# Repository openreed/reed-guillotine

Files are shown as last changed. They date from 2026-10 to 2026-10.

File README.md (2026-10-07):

# Reed Guillotine

[Read in English](README.md) | [[以中文阅读](README_CN.md)]

> OpenSCAD parametric model source for the OpenReed reed guillotine.
> For product info, visit the [project page](https://openreed.github.io/oboe/reed-guillotine/).

---

## Table of Contents

- [Reed Guillotine](#reed-guillotine)
  - [Table of Contents](#table-of-contents)
  - [Generating 3D Model Files](#generating-3d-model-files)
    - [Prerequisites](#prerequisites)
    - [Using the Render Script](#using-the-render-script)
    - [Pre-generated Files](#pre-generated-files)
  - [Parameter Reference](#parameter-reference)
  - [3D Printing Tips](#3d-printing-tips)
  - [Project Structure](#project-structure)
  - [License](#license)

---

## Generating 3D Model Files

### Prerequisites

- [OpenSCAD](https://openscad.org/) (recommended: `brew install openscad` on macOS)
- Python 3
- [BOSL2](https://github.com/revarbat/BOSL2) library — install via OpenSCAD's Library Manager

### Using the Render Script

The project provides `render.py` to render all parts to STL in one command:

```bash
# Render all parts of the oboe/English horn version
python render.py obeh

# Render only specific parts (comma-separated)
python render.py obeh --parts body,lid,handle

# Render assembly only
python render.py obeh --assembly-only

# Custom output directory
python render.py obeh --output ./my_stls

# List available model versions
python render.py --list-versions
```

STL files are saved to `3D_files/obeh/` by default.

### Pre-generated Files

Pre-generated `.3mf` files are also available for direct download from MakerWorld.

---

## Parameter Reference

All parameters are defined in `libs/obeh/params.scad`. See the [Chinese README](README_CN.md#参数说明) for the complete parameter table with descriptions.

The assembly uses one fixed lower blade and a solid upper cutting block. The block uses `cutting_block_wedge_height=3` mm and `cutting_block_tip_radius=1.2` mm. Open `assembly.scad` or run `python3 render.py obeh --assembly-only` to render the assembly. `blade_holder.scad` renders only the lower blade clamp.

The cutting block forms its rounded wedge with `hull()` between the block shoulder and a cylinder. The radius may exceed half the wedge height: the cylinder can overlap the solid main block. Radius changes preserve the finished block height (`blade_width`) and contact ridge position. Positive `blade_engagement_tolerance` leaves clearance at the lowest position, while negative values allow engagement. This is the signed height difference between the block's lowest point and the lower blade at the geometric spring-seat stop. Actual travel also depends on the installed spring and handle.

`cutting_block_front_back_fit_tolerance` shifts the block's contact edge along x relative to the lower blade. The body, slider positions in the assembly, and lower blade clamp stay fixed. The independent lower clamp thickness, `blade_clamp_height`, defaults to 1.885 mm to preserve the existing body dimensions. Block slider and slot parameters use the `cutting_block_` prefix.

The parameters are organized into the following groups:

| Group | Description |
|---|---|
| Tolerances | Fine-tune part fit and assembly clearance |
| Base Parameters | Main body dimensions and fillets |
| Slot Parameters | Reed holder slot geometry |
| Scale Parameters | Cutting scale markings |
| Blade Parameters | Standard utility blade (009 RD) dimensions |
| Blade Holder Parameters | Blade clamp geometry |
| Cutting Block Parameters | Block sliders, wedge height, and contact edge radius |
| Spring Parameters | Spring seat dimensions |
| Wall Parameters | Side walls and screw holes |
| Handle Parameters | Handle and axle geometry |
| Lid Parameters | Top lid dimensions |
| Reed Holder Parameters | Reed holder, staple slot, and mandrel dimensions |

---

## 3D Printing Tips

- Use ≤ 0.12 mm layer height for the lower blade clamp, cutting block, and reed holder
- Print the cutting block with its flat back on the bed and the rounded wedge facing up
- Enable supports for the reed holder
- Multi-color printing makes scale markings more readable
- **PETG** is recommended for better durability

---

## Project Structure

```
├── README.md              # This file
├── render.py              # STL rendering script
├── draft.scad / draft2.scad  # Scratch files
├── libs/
│   ├── obeh/              # Oboe / English Horn version
│   │   ├── params.scad    # All parameter definitions
│   │   ├── assembly.scad  # Assembly model
│   │   └── modules/       # Individual part modules
│   │       ├── body.scad
│   │       ├── blade.scad
│   │       ├── blade_holder.scad
│   │       ├── cutting_block.scad
│   │       ├── handle.scad
│   │       ├── lid.scad
│   │       └── reed_holder.scad
│   └── utils/
│       └── utils.scad     # Utility module
├── 3D_files/
│   └── obeh/
│       └── reed-guillotine.3mf  # Pre-generated file
└── assets/                # Assets
```

---

## License

MIT License — © 2026 OpenReed Project

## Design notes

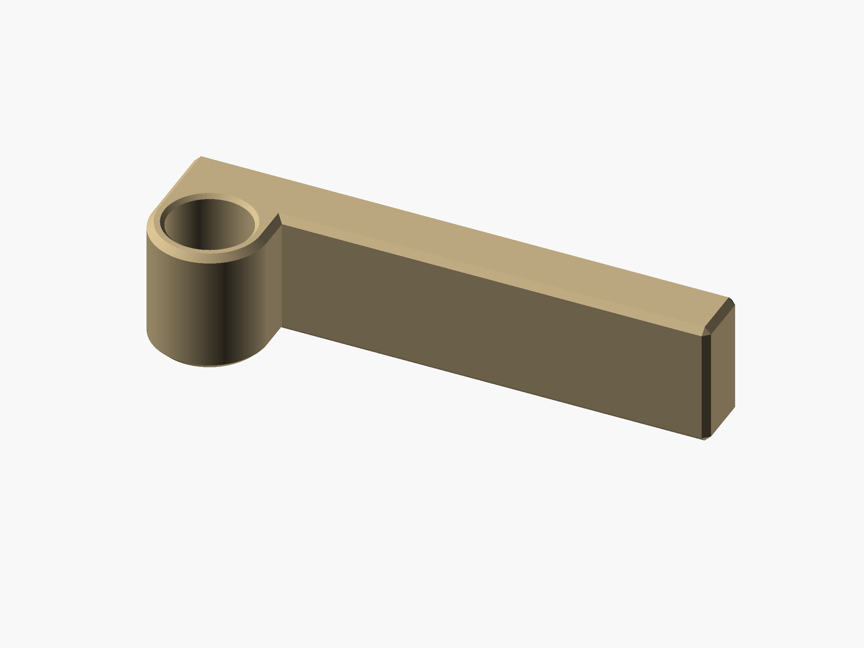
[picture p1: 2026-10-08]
assets/obeh/handle.png

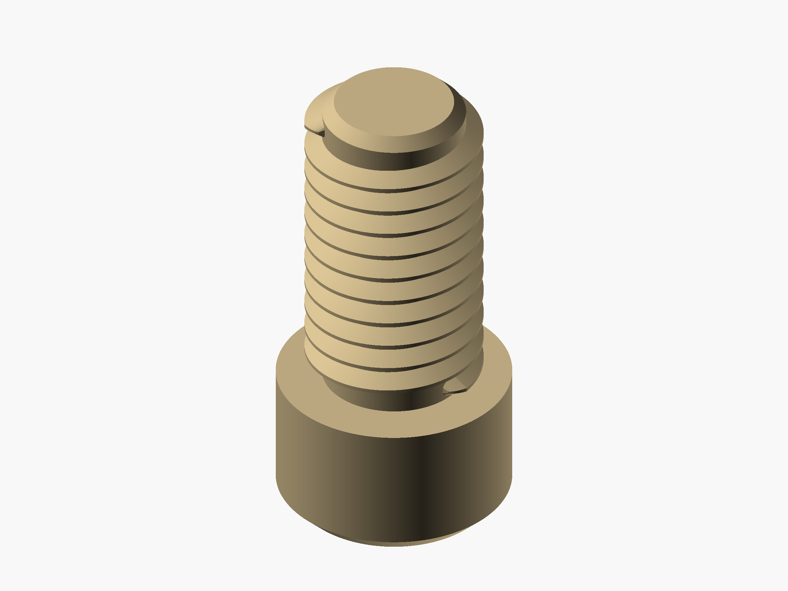
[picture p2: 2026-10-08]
assets/obeh/tightening-screw.png

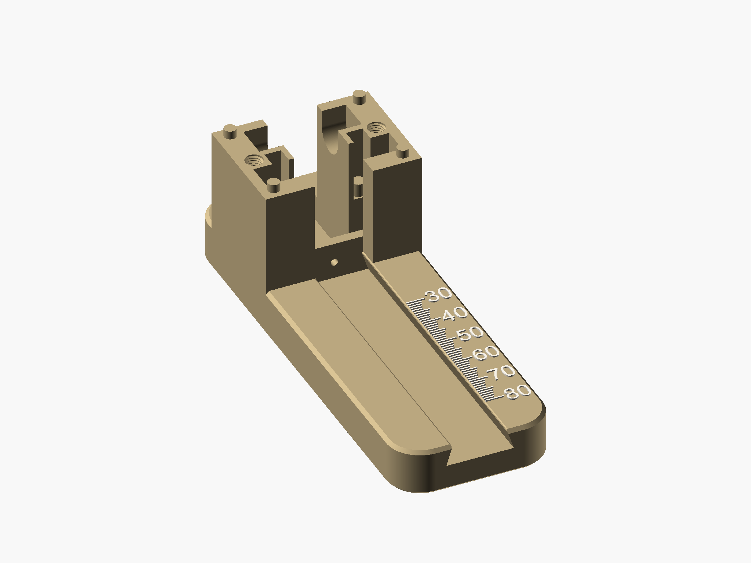
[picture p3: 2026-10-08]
assets/obeh/body.png

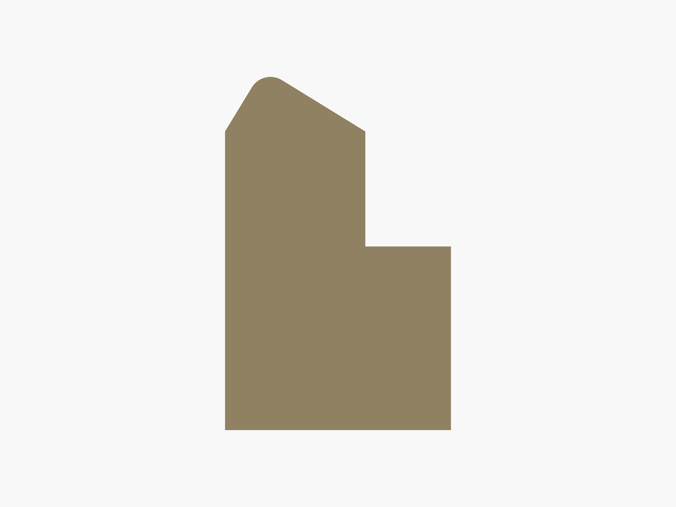
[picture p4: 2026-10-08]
assets/obeh/cutting-block-side.png

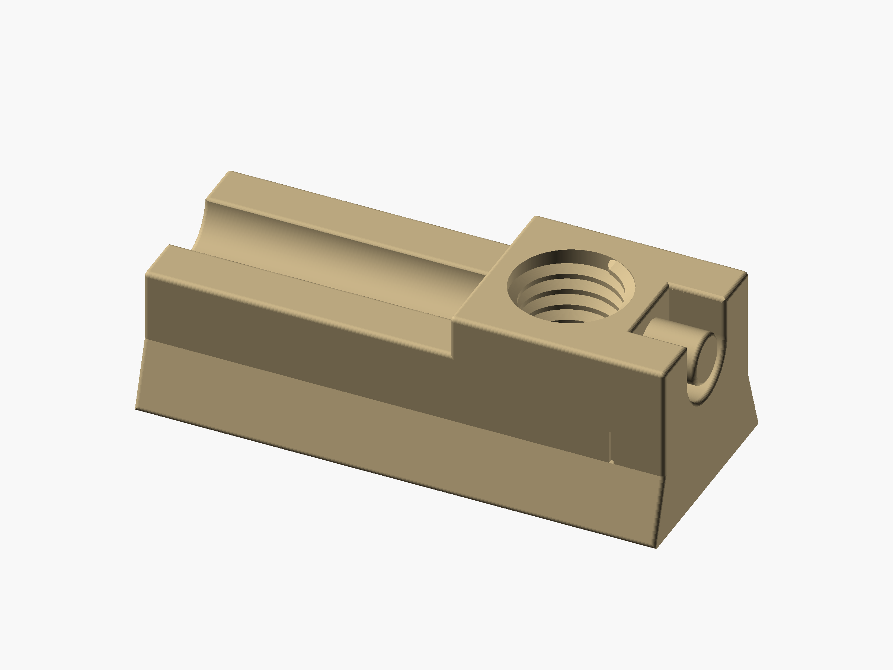
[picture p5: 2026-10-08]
assets/obeh/reed-holder.png

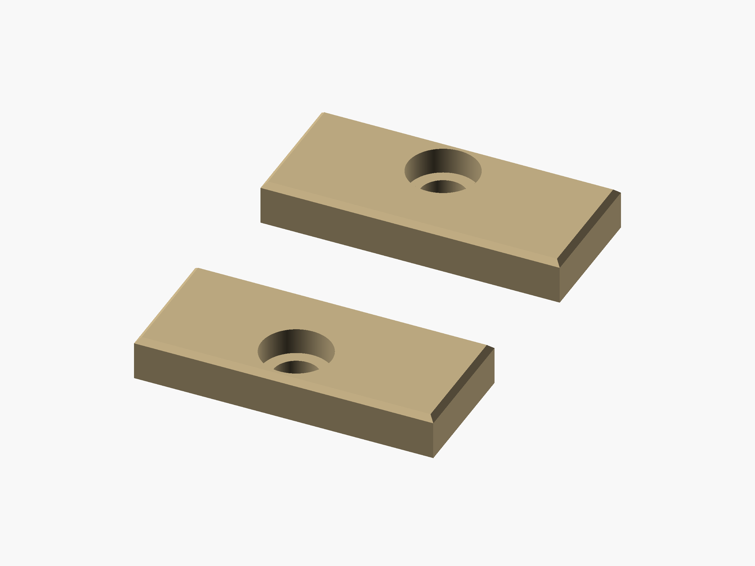
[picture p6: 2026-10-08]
assets/obeh/lid.png

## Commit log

2026-03-16 Building the body, finish the reed holder slot.
2026-04-21 Building walls, adjusting blade holders and clamps.
2026-05-06 Finish the tightening screw.
2026-05-10 Adjust reed holder, assemble the parts.
2026-05-24 Add more tongues on the body and more grooves on the lid, and cut a slot to avoid interference between the base and the screw driver when tightening the screw on the bottom blade.
2026-06-04 Adjust reed holder staple slot, blade hole size, and lid back.
2026-06-19 Adjust some parameters, and let bottom and upper blade clamp have equal height.
